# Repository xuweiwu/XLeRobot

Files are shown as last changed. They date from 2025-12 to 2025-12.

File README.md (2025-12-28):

# [XLeRobot 🤖](https://xlerobot.readthedocs.io/en/latest/index.html)




<a href="https://xlerobot.readthedocs.io/en/latest/index.html">
  front
</a>





---

**🚀 Bringing Embodied AI to Everyone - Cheaper Than an iPhone! 📱**  
**💵 Starts from $660 cost and ⏰ <4hrs total assembly time!!**

*Built upon the giants: [LeRobot](https://github.com/huggingface/lerobot), [SO-100/SO-101](https://github.com/TheRobotStudio/SO-ARM100), [Lekiwi](https://github.com/SIGRobotics-UIUC/LeKiwi), [Bambot](https://github.com/timqian/bambot)*

<table>
  <tr>
    <td></td>
    <td></td>
    <td></td>
  </tr>
  <tr>
    <td></td>
    <td></td>
    <td></td>
  </tr>
  <tr>
    <td></td>
    <td></td>
    <td></td>
  </tr>
</table>

---

# 📰 News 
- 2025-12-02: [Dual-wheel version released](https://github.com/Vector-Wangel/XLeRobot/blob/main/hardware/XLeRobot_0_4_0_extra.stl)! Have a more stable and accurate differential-wheel base for a cheaper price. (Default servo motor, optional scooter brushless Motor available at a similar price)
  

- 2025-11-11: **[Temporary VLA tutorial](https://xlerobot.readthedocs.io/en/latest/software/getting_started/RL_VLA.html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)** out. Official version out soon.
- 2025-09-22: **Hardware Assembly Video Tutorial** availabe at [Youtube](https://www.youtube.com/watch?v=upB1CEFeOlk) and [Bilibili](https://www.bilibili.com/video/BV1AGWFzUEJf/). Thanks WOWROBO for making this video!
- 2025-09-09: **Developer Assembly kit (excluding battery and IKEA cart) ready for purchase** in [China (Taobao) for **3699￥**](https://e.tb.cn/h.SZFbBgZABZ8zRPe?tk=ba514rTBRjQ) and [world-wide for **579\$**](https://shop.wowrobo.com/products/xlerobot-dual-arm-mobile-household-robot-kit?variant=47297659961561). _(In collaboration with **Wowrobo**)_
  
  - Non-profit, I personally don't earn any from this. I also asked Wowrobo to set the price as low as possible.
  - This is only the assembly kit for developers, please check documentation website and this repo for available codes and tutorials before you purchase.
- 2025-09-09: Joined [Embodied AI Home Robot Hackathon](https://www.seeedstudio.com/embodied-ai-worldwide-hackathon-home-robot.html) (Oct 25–26, Bay Area) held by **SEEED x Nvidia x Huggingface** as mentor! [Register HERE](https://docs.google.com/forms/d/e/1FAIpQLSdYYDegdgIypxuGJNLcoc8kbdmU4jKgl49zg4X-107LAmBN4g/viewform).
- 

- 2025-08-30: XLeRobot 0.3.0 Release with final outfit touch up and household chores showcase demos. 

- 2025-07-30: [Control XLeRobot in real life](https://xlerobot.readthedocs.io/en/latest/software/index.html) with **keyboard/Xbox controller/Switch joycon** in the wild anywhere. All bluetooth, no wifi needed and zero latency.

- 2025-07-08: [**Simulation**](https://xlerobot.readthedocs.io/en/latest/simulation/index.html) with updated urdfs, control scripts (support Quest3 VR, keyboard, Xbox controller, switch joycon), support for new hardware and cameras, RL environment. Get started in 15 min.
-  vr

- 2025-07-01: [**Documentation** website](https://xlerobot.readthedocs.io/en/latest/index.html) out for more orgainized tutorials, demos and resources.

- 2025-06-13: [**XLeRobot 0.2.0**](https://xlerobot.readthedocs.io) hardware setup, the 1st version fully capable for autonomous household tasks, starts from 660$. 

---

## 💵 Total Cost 💵

> [!NOTE] 
> Cost excludes 3D printing, tools, shipping, and taxes.

| Price (Buy all the parts yourself) | US | EU | CN | IN |
| --- | --- | --- | --- | --- |
| **Basic** (use your laptop, single RGB head cam) | **~$660** | **~€680** | **~¥3999** | **~₹87000** |
| ↑ Stereo dual-eye RGB head cam | +$30 | +€30 | +¥199 | +₹6550 |
| + RasberryPi | +$79 | +€79 | +¥399 | +₹7999 |
| ↑ RealSense RGBD head cam | +$220 | +€230 | +¥1499 | +₹35726 |

---
## 🚀 Get Started 🚀

> [!NOTE] 
> If you are totally new to programming, please spend at least a day to get yourself familiar with basic Python, Ubuntu and Github (with the help of Google and AI). At least you should know how to setup ubuntu system, git clone, pip install, use intepreters (VS Code, Cursor, Pycharm, etc.) and directly run commands in the terminals.

1. 💵 **Buy your parts**: [Bill of Materials](https://xlerobot.readthedocs.io/en/latest/hardware/getting_started/material.html)
2. 🖨️ **Print your stuff**: [3D printing](https://xlerobot.readthedocs.io/en/latest/hardware/getting_started/3d.html)
3. 🔨 ~~Avengers~~: [**Assemble**!](https://xlerobot.readthedocs.io/en/latest/hardware/getting_started/assemble.html)
4. 💻 **Software**: [Get your robot moving!](https://xlerobot.readthedocs.io/en/latest/software/index.html)

---

## Contribute

**👋 Want to contribute to XLeRobot?**
Please refer to [CONTRIBUTING.md](CONTRIBUTING.md) for guidance on how to get involved!

**Main Contributors**

- [Gaotian/Vector Wang](https://vector-wangel.github.io/)
- Jiahao Wang ,Chunbo Pan, QiLiu, Isaac Sin, Ryan Chen: Makermods team, VLA and VR integration
- [Zhuoyi Lu](https://lzhuoyi.github.io/Zhuoyi_Lu.github.io/): RL sim2real deploy, teleop on real robot (Xbox, VR, Joycon)
- Yiyang Huang: RL & VLA implementation (ongoing)
- YCP: WebUI for remote control (ongoing)
- [Lixing Zhang](lixingzhang.com): Hardware design improvements
- Nicole Yue: Documentation website setup
- Yuesong Wang: Mujoco simulation

This is just a small brick in the pyramid, made possible by [LeRobot](https://github.com/huggingface/lerobot), [SO-100](https://github.com/TheRobotStudio/SO-ARM100), [Lekiwi](https://github.com/SIGRobotics-UIUC/LeKiwi), and [Bambot](https://github.com/timqian/bambot). Thanks to all the talented contributors behind these detailed and professional projects.

Looking forward to collaborating with anyone interested in contributing to this project!

## About me

[Gaotian/Vector Wang](https://vector-wangel.github.io/)

I am a CS graduate student at Rice University [RobotPi Lab](https://robotpilab.github.io/), focusing on robust object manipulation, where we propse virtual cages and funnels and physics-aware world models to close the Sim2real gap and achieve robust manipulation under uncertainties. One of my papers, Caging in Time, has recently been accepted by International Journal of Robotics Research (IJRR).

I built XLeRobot as a personal hobby to instantiate my research theory, also to provide a low-cost platform for people who are interested in robotics and embodied AI to work with. 

Star History Chart (https://star-history.com/#Vector-Wangel/XLeRobot&Timeline)
---

## Citation

If you want, you can cite this work with:

```bibtex
@misc{wang2025xlerobot,
    author = {Wang, Gaotian and Lu, Zhuoyi},
    title = {XLeRobot: A Practical Low-cost Household Dual-Arm Mobile Robot Design for General Manipulation},
    howpublished = "\url{https://github.com/Vector-Wangel/XLeRobot}",
    year = {2025}
}
```
---Generated Image August 27, 2025 - 4_58PM

## 🪧 Disclaimer 🪧

> [!NOTE]
> If you build, buy, or develop a XLeRobot based on this repo, you will be fully responsible for all the physical and mental damages it does to you or others.

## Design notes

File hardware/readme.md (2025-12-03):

Here stores the .3mf file of XLeRobot 0.3.0 for 3D printing.



Note that the 3D Printing files are only to store the models. It’s suggested to place, orient, and add supports yourself to ensure the best printing quality.

## Notes
- New release on XLeRobot 0.4.0: dual-wheel setup, more versatile arm base (choose your own mounting direction).
- The .3mf file contains soft finray fingers that need to be printed with TPU95A. If you want original SO101 finger, just download the original SO101 .stl file.
- d2e57534a9e55a3d4dc0d644242cd044
- The .3mf file contains 2 version of the single RGB head camera connector and shell, one for webcam & realsense, the other for the cheaper camera same as the hand camera.
- 

- No need to adjust the base connector this time, just print the washers and insert them into the IKEA cart for the best base support.
- 

---

- Update 20.09.2025 by Lix: New gimbal designs can be found in the two mesh files:
    - Gimbal_Pitch_Holder_d435.stl: For Intel Realsense D435 or similar RGBD camera.
    - Gimbal_Pitch_Holder_d455.stl: For Intel Realsense D455 or similar RGBD camera.

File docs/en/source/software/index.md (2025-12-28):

<!-- THIS IS ALL GENERATED DOCUMENTATION via generate_robot_docs.py. DO NOT MODIFY THIS FILE DIRECTLY. -->

# Software

Here we will show how to run XLeRobot under the lerobot framework.

### [Install LeRobot 🤗 and Move XLeRobot files](getting_started/install.md)

### Quick Guide

```{note}
If you haven't played with lerobot SO101 Arm before, it's recommended to test single arm setup teleop and play with it for a while first.
```

1. **Choose Control Method**: Joint control (example 0) for basic motor testing, end-effector control for teleop (example 1 & 6)
2. **Advanced Features**: Try dual-arm control (example 2) or vision-based control (example 3) for more complex tasks
3. **Full System**: Use keyboard (example 4), Xbox controller (example 5), or Switch Joycon (example 7) for complete XLeRobot teleop

All example scripts are located in the [`software/examples/`](https://github.com/Vector-Wangel/XLeRobot/tree/main/software/examples) directory and can be run directly after proper setup and calibration. Some examples needs additional calibration to ensure performance.

```{note}
For basic version of XLeRobot, you don't need a RaspberryPi. Just use your laptop and put it in the IKEA cart if you want to use the full system.
```

### [SO100/SO101 Arm Examples](getting_started/SO101.md)

### [XLeRobot Teleop](getting_started/XLeRobot_teleop.md)

### [Autonomous LLM Agent](getting_started/LLM_agent.md)

```{note}
The VLA tutorials below came from different teams in the community. Thanks a lot for their efforts!
```

### [VLA (1) ACT](getting_started/VLA_ACT.md)

### [VLA (2) SmolVLA)](getting_started/VLA_smol.md)

### [VLA (3) pi0.5)](getting_started/VLA_pi05.md)

### [Reinforcenment Learning (RL)](getting_started/RL.md)

### [Raspberri Pi Setup](getting_started/raspberry_pi_setup.md)

```{toctree}
getting_started/install
getting_started/SO101
getting_started/XLeRobot_teleop
getting_started/LLM_agent
getting_started/VLA_ACT
getting_started/VLA_smol
getting_started/VLA_pi05
getting_started/RL
getting_started/raspberry_pi_setup.md
```

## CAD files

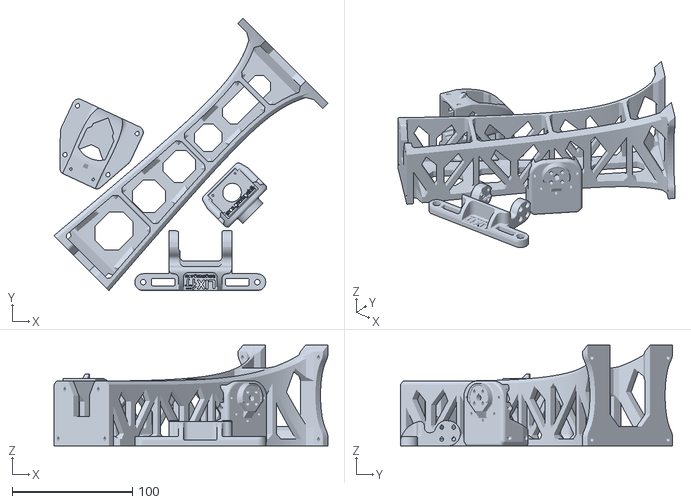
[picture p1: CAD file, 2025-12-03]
hardware/camera_connector/Gimbal_mesh_all_d455.stl
228.0 x 226.5 x 84.0

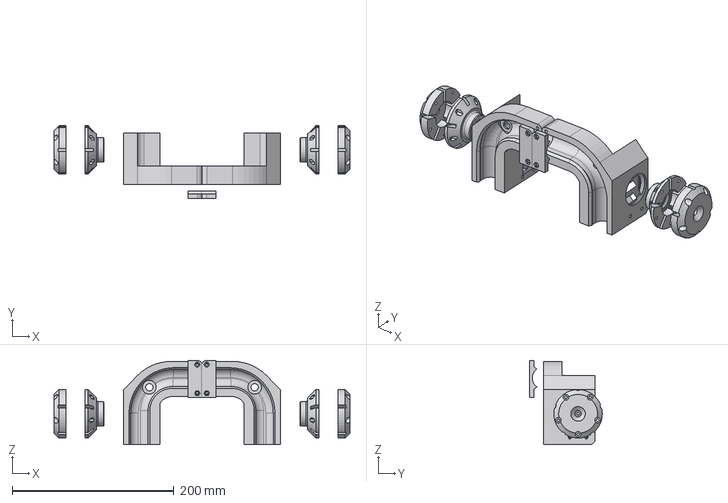
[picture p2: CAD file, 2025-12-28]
hardware/step/XLeRobot_040/XLeRobot040_dualwheelbase.step
366.3 x 89.9 x 104.3 mm
Circular Pattern 01
omni_wheel_mount v5:3

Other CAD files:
hardware/camera_connector/Gimbal_mesh_all_d435.stl

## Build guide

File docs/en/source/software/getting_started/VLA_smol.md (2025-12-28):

# VLA (2) SmolVLA, ACT

This document explains how to use **XLeRobot** for:
1. Training and running **SmolVLA** with a **bimanual SO-101** setup and **three-camera data collection**
2. Training and running **ACT (Action Chunking with Transformers)** policy
3. Using **VR Control** for XLeRobot
VR Demo GIF
VR Demo GIF
---

## 1) Overview

XLeRobot is a LeRobot-based setup that adds:
- **BiSO101Follower** (bimanual follower arm)
- **BiSO101Leader** (bimanual teleoperation/leader arm)
- **Independent** control of left/right arms + **synchronized** bimanual operation
- **Three-camera** recording configuration:
  - `front_cam`
  - `hand_cam`
  - `side_cam`
 

### References
- [SmolVLA base model](https://huggingface.co/lerobot/smolvla_base)
- [ACT documentation](https://huggingface.co/docs/lerobot/en/act)
- [XLeRobot / LeRobot fork usage](https://github.com/kahowang/lerobot)
- [Rumi](https://github.com/MakerModsRobotics/Rumi)
- [XLeRobot improvement upgrades](https://github.com/MakerModsRobotics/xlerobot_improvements)

---

## 2) Demo Tasks (What SmolVLA Can Learn with ~20 Episodes)

### Demo 1 - Drawer + Pick + Place + Grasp (Bimanual)
After training on **~20 episodes**, XLeRobot can:
1. Pull open a drawer
2. Pick an object
3. Place the object into the drawer
4. Push the drawer in

VR Demo GIF

**Key aspects:**
- **One-shot grasp** of the drawer handle (avoid jitter during data collection)
- While the **left arm** pulls the drawer, the **right arm** must **precisely** grasp the object's center
- **Accurate one-shot placement** into the drawer and smooth "push-in" close

### Demo 2 - Pencil Case Zipper (Fine Manipulation)
After training on **~20 episodes**, XLeRobot can:
1. Grasp the zipper pull tab
2. Grasp the pencil case handle and stabilize the case
3. Pull the zipper tab to open the zipper smoothly

VR Demo GIF

**Key difficulties:**
- The zipper pull is often in a **top-down camera blind spot**, requiring **one-shot** grasp (avoid re-grasp)
- Maintain consistent pulling height to avoid lifting up/down (no "upward yank" or "downward drag")

---

## 3) Hardware / Configuration Notes

### Camera Placement (Three Cameras)
Recommended configuration:
- `front_cam` × 1
- `hand_cam` × 1
- `side_cam` × 1

> **Note:** In practice, consistent camera placement and stable lighting are critical for learning stable manipulation.

### Action Dimension Handling (Important)
A bimanual SO-101 robot has **12 action dimensions**:
- 6 joints × 2 arms = **12**

**SmolVLA automatically detects and handles action dimensions** without manual configuration:
- During training: **12-D → padded to 32-D** (`max_action_dim`)
- During inference: **32-D → cropped back to original 12-D**

**Conceptual code path:**
```python
# Training: 12D -> pad to 32D
actions = pad_vector(batch[ACTION], self.config.max_action_dim)

# Inference: 32D -> crop back to 12D
original_action_dim = self.config.action_feature.shape[0]  # auto-detected: 12
actions = actions[:, :, :original_action_dim]
```

Unlike other VLA models (e.g., xVLA) that may require manual `action_mode` configuration, SmolVLA's dynamic padding supports any action space ≤ 32D.

---

## 4) Installation & Environment Setup (Linux)

### A. Install Miniconda (Example)
```bash
wget https://repo.anaconda.com/miniconda/Miniconda3-latest-Linux-x86_64.sh
bash Miniconda3-latest-Linux-x86_64.sh

# Restart terminal, then verify
conda --version
```

### B. Create & Activate Environment
```bash
conda create -n lerobot python=3.10
conda activate lerobot
```

> **Note:** Activate this environment every time you use LeRobot/XLeRobot:
> ```bash
> conda activate lerobot
> ```

### C. Install System Dependencies (FFmpeg)
```bash
conda install -c conda-forge ffmpeg
```

### D. Clone Repository & Install Dependencies
```bash
git clone https://github.com/kahowang/lerobot.git
cd lerobot

# Install LeRobot with Feetech motor support (required for SO-101)
pip install -e ".[feetech]"

# Install SmolVLA dependencies
pip install -e ".[smolvla]"
```

---

## 5) Data Collection (Three-Camera, Bimanual Teleop)

Use `lerobot-record` to record bimanual demonstrations with three cameras.

Replace `${HF_USER}` and `your_dataset_name` with your Hugging Face username and dataset name.

```bash
lerobot-record \
  --robot.type=bi_so101_follower \
  --robot.left_arm_port=/dev/ttyACM0 \
  --robot.right_arm_port=/dev/ttyACM1 \
  --robot.id=bimanual_follower \
  --robot.cameras='{
    "front_cam": {"type": "opencv", "index_or_path": 0, "width": 640, "height": 480, "fps": 30},
    "hand_cam": {"type": "opencv", "index_or_path": 1, "width": 640, "height": 480, "fps": 30},
    "side_cam": {"type": "opencv", "index_or_path": 2, "width": 640, "height": 480, "fps": 30}
  }' \
  --teleop.type=bi_so101_leader \
  --teleop.left_arm_port=/dev/ttyACM2 \
  --teleop.right_arm_port=/dev/ttyACM3 \
  --teleop.id=bimanual_leader \
  --dataset.repo_id=${HF_USER}/your_dataset_name \
  --dataset.single_task="Your task description here" \
  --dataset.num_episodes=50
```

### Parameter Tips
1. Ports (`/dev/ttyACM*`) must match your actual USB device mapping
2. `dataset.single_task` should be concise but specific (improves reproducibility)
3. For quick iteration, start with 20 episodes and scale up

---

## 6) Training Policies

### 6.1) Train SmolVLA

```bash
lerobot-train \
  --policy.path=lerobot/smolvla_base \
  --dataset.repo_id=${HF_USER}/your_dataset_name \
  --batch_size=64 \
  --steps=20000 \
  --output_dir=outputs/train/smolvla_three_cameras \
  --job_name=smolvla_training_three_cameras \
  --policy.device=cuda \
  --wandb.enable=true
```

**Notes:**
1. `--policy.path=lerobot/smolvla_base` points to the SmolVLA base policy
2. Adjust `--steps` based on dataset size and task complexity
3. If you do not have a GPU, set `--policy.device=cpu` (training will be slow)

### 6.2) Train ACT (Action Chunking with Transformers)

ACT is an imitation-learning method that predicts short action chunks instead of single steps. It often achieves high success rates with teleoperated data.

**Basic Training Command:**
```bash
python -m lerobot.scripts.train \
  --dataset.repo_id=${HF_USER}/your_dataset_name \
  --policy.type=act \
  --output_dir=outputs/train/act_bimanual_demo \
  --job_name=act_training_bimanual \
  --policy.device=cuda \
  --policy.repo_id=${HF_USER}/act_bimanual_demo \
  --wandb.enable=true
```

**Alternative using `lerobot-train`:**
```bash
lerobot-train \
  --policy.type=act \
  --dataset.repo_id=${HF_USER}/your_dataset_name \
  --output_dir=outputs/train/act_bimanual_demo \
  --job_name=act_training_bimanual \
  --policy.device=cuda \
  --wandb.enable=true
```

**Training Notes:**
- Checkpoints are written to `outputs/train/<job_name>/checkpoints/`
- ACT typically trains in a few hours on a single GPU (~80M parameters)
- A checkpoint at 80k steps takes about 1h45 on an Nvidia A100
- For Apple Silicon: use `--policy.device=mps`

**Resume Training from Checkpoint:**
```bash
python -m lerobot.scripts.train \
  --config_path=outputs/train/act_bimanual_demo/checkpoints/last/pretrained_model/train_config.json \
  --resume=true
```

---

## 7) Inference/Evaluation

### 7.1) SmolVLA Inference

Typical pattern to run policy inference and log evaluation episodes:

```bash
lerobot-record \
  --robot.type=bi_so101_follower \
  --robot.left_arm_port=/dev/ttyACM0 \
  --robot.right_arm_port=/dev/ttyACM1 \
  --robot.id=bimanual_follower \
  --robot.cameras='{
    "front_cam": {"type": "opencv", "index_or_path": 0, "width": 640, "height": 480, "fps": 30},
    "hand_cam": {"type": "opencv", "index_or_path": 1, "width": 640, "height": 480, "fps": 30},
    "side_cam": {"type": "opencv", "index_or_path": 2, "width": 640, "height": 480, "fps": 30}
  }' \
  --dataset.single_task="Your task description here" \
  --dataset.repo_id=${HF_USER}/eval_results \
  --dataset.num_episodes=10 \
  --policy.path=${HF_USER}/smolvla_three_cameras
```

**Notes:**
1. `--policy.path` should point to your trained policy checkpoint / uploaded policy
2. `eval_results` is a separate dataset repo for evaluation logs (recommended)

### 7.2) ACT Inference

**Using `lerobot-record`:**
```bash
lerobot-record \
  --robot.type=bi_so101_follower \
  --robot.left_arm_port=/dev/ttyACM0 \
  --robot.right_arm_port=/dev/ttyACM1 \
  --robot.id=bimanual_follower \
  --robot.cameras='{
    "front_cam": {"type": "opencv", "index_or_path": 0, "width": 640, "height": 480, "fps": 30},
    "hand_cam": {"type": "opencv", "index_or_path": 1, "width": 640, "height": 480, "fps": 30},
    "side_cam": {"type": "opencv", "index_or_path": 2, "width": 640, "height": 480, "fps": 30}
  }' \
  --dataset.single_task="Your task description here" \
  --dataset.repo_id=${HF_USER}/eval_act_results \
  --dataset.num_episodes=10 \
  --policy.path=${HF_USER}/act_bimanual_demo
```

**Using `python -m lerobot.record`:**
```bash
python -m lerobot.record \
  --robot.type=bi_so101_follower \
  --robot.left_arm_port=/dev/ttyACM0 \
  --robot.right_arm_port=/dev/ttyACM1 \
  --dataset.repo_id=${HF_USER}/eval_act_results \
  --policy.path=${HF_USER}/act_bimanual_demo \
  --episodes=10
```

**Notes:**
- The policy will execute autonomously on the robot
- Evaluation results are saved to the specified dataset repo
- Compare evaluation episodes with training demonstrations to assess performance

---

## 8) VR Control for XLeRobot

VR Demo GIF

### Robot: Rumi
Rumi is a new-generation bimanual robot with a liftable chassis:
[Rumi](https://www.makermods.ai/rumi)

RUMI_HEAD_VR

### Repositories
1. [VR controller repo](https://github.com/IIMFINE/lerobot_vr_controller.git)
2. [LeRobot repo (fork)](https://github.com/IIMFINE/lerobot.git)

### Features
1. VR → robot arm mapping
2. Supports:
   - Inverse kinematics (IK) solving
   - Joint-space → motor command conversion

### XLeRobot integrates ROS 2
For VR control, follow the repository's README to configure VR devices, ROS 2 nodes, and robot drivers.

---

VR Demo GIF

## 9) Practical Tips / Common Pitfalls

### Data Quality
1. Aim for one-shot grasps during demonstrations (avoid micro-corrections)
2. Keep camera viewpoints consistent between recording and inference
3. Maintain stable lighting and avoid motion blur

### Bimanual Coordination
For tasks like drawers:
- **Left arm:** stable pulling trajectory
- **Right arm:** precise pick/place with minimal hesitation

VR Demo GIF

### Device Ports
If ports change after reboot, consider using persistent udev rules to stabilize device naming.
---

VR Demo GIF

## 10) Quick Checklist

- [ ] `conda activate lerobot`
- [ ] Three cameras connected and indices correct (0/1/2)
- [ ] Follower ports correct (`/dev/ttyACM0`, `/dev/ttyACM1`)
- [ ] Leader ports correct (`/dev/ttyACM2`, `/dev/ttyACM3`)
- [ ] Dataset repo ID and task description set
- [ ] Training runs on correct device (cuda vs cpu)
- [ ] Inference uses the correct trained policy path

---

<video width="100%" controls>
  <source src="https://vector-wangel.github.io/XLeRobot-assets/videos/Community/makermod/makermod.mp4" type="video/mp4">
  Your browser does not support the video tag.
</video>

## Appendix: Links

### Official Documentation
- [LeRobot Docs](https://huggingface.co/docs/lerobot)
- [ACT Documentation](https://huggingface.co/docs/lerobot/en/act)
- [Imitation Learning on Real-World Robots](https://huggingface.co/docs/lerobot/il_robots)
- [Getting Started with Real-World Robots](https://huggingface.co/docs/lerobot/en/getting_started_real_world_robot)

### Models & Repositories
- [SmolVLA base](https://huggingface.co/lerobot/smolvla_base)
- [ACT example model](https://huggingface.co/lerobot/act_aloha_sim_transfer_cube_human)
- [XLeRobot fork usage](https://github.com/kahowang/lerobot)
- [Rumi robot](https://www.makermods.ai/rumi)
- [VR controller](https://github.com/IIMFINE/lerobot_vr_controller.git)
- [LeRobot fork](https://github.com/IIMFINE/lerobot.git)

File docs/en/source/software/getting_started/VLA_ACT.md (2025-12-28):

## VLA (1) ACT

Single arm VLA policy implementation on XLeRobot:

<video width="100%" controls>
  <source src="https://vector-wangel.github.io/XLeRobot-assets/videos/Real_demos/Act_on_RPi_Xle.mp4" type="video/mp4">
  Your browser does not support the video tag.
</video>

# Vision-Language-Action (VLA) Training for XLeRobot

This tutorial will guide you through the process of training a Vision-Language-Action (VLA) model to control your XLeRobot arms autonomously. As control devices we will use VR and leader arm. If you want us to add more control devices (as xbox controller or keyboard) feel free to open an issue.

## What You'll Learn

1. How to teleoperate and record demonstration datasets for XLeRobot
2. How to train and evaluate your policy
3. How to make the policy work effectively

By following these steps, you'll be able to train your XLeRobot to autonomously perform various household tasks using LeRobot policies (such as ACT), including picking up objects, wiping tables, or organizing items.

---

## 1. Hardware Setup and Check

### 1.1 Turn the head camera to an appropriate angle

For both VLA dataset collection and inference you need to keep consistent head servos angles - otherwise policy will not work or performance will drop.

Also, ensure the camera fully sees arms operation field - if for example your policy takes object from table and puts it into robot basket - both table and basket need to be fully visible.

You can turn the camera by your hand or use utility from RoboCrew lib (especially if you want to use your VLA policy as LLM agent tool) - this will provide you with a perfect repeatability of the camera angle:

```python
from robocrew.robots.XLeRobot.servo_controls import ServoControler

servo_controler = ServoControler(left_arm_head_usb='/dev/arm_left')
servo_controler.turn_head_to_vla_position()
```

### 1.2 Check Camera Status

Use the LeRobot [cameras](https://huggingface.co/docs/lerobot/cameras) tutorial to verify your camera setup:

```bash
lerobot-find-cameras opencv  # or use 'realsense' for Intel RealSense cameras
```

You should see output similar to this:

```
--- Detected Cameras ---
Camera #0:
  Name: OpenCV Camera @ 0
  Type: OpenCV
  Id: 0
  Backend api: AVFOUNDATION
  Default stream profile:
    Format: 16.0
    Width: 1920
    Height: 1080
    Fps: 15.0
--------------------
(more cameras ...)
```

XLeRobot has three cameras: two wrist cameras and one head camera. Make sure all three are detected.

---

## 2.1. Record Dataset for a Single Arm Using a Leader Arm

Very often the single arm is enough to perform your pick-and-place task. Using single arm only means using less servos and cameras, so it will be much easier for your model to learn the policy. If your task is simple enough to be done with one arm - let's train policy for it.

Connect a leader arm to the Raspberry Pi or other computer you use to record a dataset.

Following script will start recording:

```bash
python /your_dir/lerobot/src/lerobot/record.py \
  --robot.type=so101_follower \
  --robot.port=/dev/right_arm \
  --robot.id=robot_right_arm \
  --robot.cameras="{ head: {type: intelrealsense, serial_number_or_name: 935422072196, width: 640, height: 480, fps: 30, use_depth: True}, right: {type: opencv, index_or_path: '/dev/video6', width: 640, height: 480, fps: 30}}" \
  --teleop.type=so101_leader \
  --teleop.port=/dev/ttyACM0 \
  --teleop.id=my_leader_arm \
  --display_data=true \
  --dataset.repo_id=your_huggingface_id/clear_table_single_arm \
  --dataset.num_episodes=50 \
  --dataset.single_task="Clear the table"
```

## 2.2. Record Dataset for XLeRobot with VR

For more complicated policies, let's use VR to activate both robot's arms and wheels.

Before the official merge into LeRobot, copy the required code from XLeRobot to LeRobot:
```bash
cp your_dir/XLeRobot/software/src/record.py your_dir/lerobot/src/lerobot/record.py
cp your_dir/XLeRobot/software/src/teleporators/xlerobot_vr your_dir/lerobot/src/lerobot/teleporators/xlerobot_vr -r
```

### Recording Script Example

Run the following script to start recording:

```bash
python /your_dir/lerobot/src/lerobot/record.py \
  --robot.type=xlerobot \
  --robot.cameras="{ head: {type: intelrealsense, serial_number_or_name: 935422072196, width: 640, height: 480, fps: 30, use_depth: True}, right: {type: opencv, index_or_path: '/dev/video6', width: 640, height: 480, fps: 20}, left: {type: opencv, index_or_path: '/dev/video8', width: 640, height: 480, fps: 20} }" \
  --dataset.repo_id=your_huggingface_id/clear_table \
  --dataset.single_task="Clear the table." \
  --dataset.root=your_dir/clear_table \
  --display_data=true \
  --teleop.type=xlerobot_vr
```

### Important Notes

1. **Camera Configuration**: The `robot.cameras` parameter should match the output from section 1.2. If you encounter camera timeout errors, reduce the FPS (e.g., from 30 to 20).

2. **VR Connection**: At the beginning of the script, it will wait for VR connection. Visit the URL displayed in the terminal output using your VR device. Data collection will start automatically once the connection is established.

3. **VR Controls**: The left-hand controller has four functions (practice several times to become familiar):
   - **Reset Position**: Returns the robot arms to their zero position
   - **Early Exit**: Ends the current episode collection (use when you've completed the task)
   - **Delete Episode**: Deletes the current episode (use if the task failed)
   - **Stop Recording**: Stops the dataset recording session

<p align="center">
  
  
</p>

---

```{note}
Some tips for a better performance:

1. **Check for Dropped Frames**: Review [these examples](https://gold-column-7d2.notion.site/Some-examples-for-VLA-dataset-2a2e20e657ad8037aa09d1228a2bf4bf?pvs=73) to understand what dropped frames look like. Monitor your bandwidth and CPU usage during recording. If issues occur, optimize your system accordingly.

2. **Avoid Redundant Frames**: Use the early exit function when the task is completed, rather than letting the script continue logging static robot data.

3. **Maintain Scene Consistency**: Avoid having additional moving objects or people in the camera view during recording.
```
---

## 3. Train a Policy

After collecting your datasets, refer to the LeRobot [training tutorial](https://huggingface.co/docs/lerobot/il_robots#train-a-policy) to select and train a policy.

## 4. Deploy a Model

The simplest way to test your trained model:
```python
python /your_dir/lerobot/src/lerobot/record.py \
  --robot.type=xlerobot \
  --robot.cameras="{ head: {type: intelrealsense, serial_number_or_name: 935422072196, width: 640, height: 480, fps: 30, use_depth: True}, right: {type: opencv, index_or_path: '/dev/video6', width: 640, height: 480, fps: 20}, left: {type: opencv, index_or_path: '/dev/video8', width: 640, height: 480, fps: 20} }" \
  --dataset.repo_id=your_huggingface_id/clear_table \
  --dataset.single_task="Clear the table." \
  --dataset.root=your_dir/clear_table \
  --display_data=true \
  --teleop.type=xlerobot_vr
```

Script above runs policy locally on your robot's Raspberry. For lightweight ACT policy it's enough, but for other more resource-consuming policies, the Raspberry will not provide enough computation. 

To run powerful policies as SmolVLA or PI0,5 we need an external computer with GPU. Follow the Lerobot [async inference guide](https://huggingface.co/docs/lerobot/async) to set up policy server on your PC, and client on the XLeRobot. Use loopback interface (0.0.0.0) instead of localhost for your server, and provide server's local IP to the client.

In most cases you'll want to use your VLA policy not by itself, but as a tool of the [LLM agent](https://xlerobot.readthedocs.io/en/latest/software/getting_started/LLM_agent.html). RoboCrew lib already provides you with async client in the tool. Before using it, remember to run policy server on the server machine:

```
python -m lerobot.async_inference.policy_server \
     --host=0.0.0.0 \
     --port=8080
```

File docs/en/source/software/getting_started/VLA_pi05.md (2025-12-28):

# VLA (3) pi0.5

<video width="100%" controls>
  <source src="https://vector-wangel.github.io/XLeRobot-assets/videos/Community/pi05_XLeRobot.mp4" type="video/mp4">
  Your browser does not support the video tag.
</video>

This document provides information about the **pi0.5** VLA (Vision-Language-Action) implementation for XLeRobot with dual-arm support.

## Overview

The pi0.5 implementation includes optimizations for data collection scripts and dual-arm teleoperation, data collection, and inference workflows. Some changes are available in local branches for reference.

## Implementation Details

### XLeRobot Fork
- **Repository**: [xuweiwu/XLeRobot](https://github.com/xuweiwu/XLeRobot)
- **Branch**: `pi05 dual arm`
- **Features**: Teleoperation, data collection, and inference for dual-arm setup

### OpenPI Fine-tuning
- **Repository**: [xuweiwu/openpi](https://github.com/xuweiwu/openpi)
- **Branch**: `biso101 training_support`
- **Features**: Training support for bimanual SO-101 configuration

## Status

A minor PR has been created to optimize the existing data collection script workflow. Additional changes that may be more difficult to merge are currently available in local branches for reference.

## Related Links

- [XLeRobot Fork (pi0.5)](https://github.com/xuweiwu/XLeRobot)
- [OpenPI Fork (biso101 training)](https://github.com/xuweiwu/openpi)

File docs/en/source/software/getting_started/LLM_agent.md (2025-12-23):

## LLM Agent Control

Imagine telling the robot "go cleanup my kitchen" and watching it doing so. This tutorial will show you how you can make your XLeRobot fully autonomous, self-decision making machine by providing it with LLM agent. An agent that uses camera vision and voice commands to move the robot and manipulate objects with VLA policies.

Demo of agent controlling XLeRobot, that has a task to grab a notebook and give it to human:

<video width="100%" controls>
  <source src="https://github-production-user-asset-6210df.s3.amazonaws.com/50213363/528949330-faf375cf-d29a-4b1b-b0b1-da474c7006fe.mov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" type="video/mp4">
  To be uploaded.
</video>

### Getting Started

To create our agent, we will use the [RoboCrew](https://github.com/Grigorij-Dudnik/RoboCrew) library - one specially designed for embodied agents. On your control device (Raspberry Pi or laptop) create a new virtual environment and install it with:

```bash
pip install robocrew
```

Next, create the python script to control your robot. Let's start by creating a simple agent that performs just one hardcoded task and finishes. 

First, let's initialize camera and create tools for agent to control a wheel movement:

```python
from robocrew.core.camera import RobotCamera
from robocrew.core.LLMAgent import LLMAgent
from robocrew.robots.XLeRobot.tools import create_move_forward, create_turn_right, create_turn_left
from robocrew.robots.XLeRobot.servo_controls import ServoControler

# set up main camera
main_camera = RobotCamera("/dev/camera_center") # camera usb port Eg: /dev/video0

#set up servo controler
right_arm_wheel_usb = "/dev/arm_right"    # provide your right arm usb port. Eg: /dev/ttyACM1
servo_controler = ServoControler(right_arm_wheel_usb=right_arm_wheel_usb)

#set up tools
move_forward = create_move_forward(servo_controler)
turn_left = create_turn_left(servo_controler)
turn_right = create_turn_right(servo_controler)
```

in place of `/dev/arm_right` you should provide the USB port name of your right arm (one connected to the wheels).

Next, let's initialize and run an agent itself:

```python
# init agent
agent = LLMAgent(
    model="google_genai:gemini-3-flash-preview",
    tools=[
        move_forward,
        turn_left,
        turn_right,
    ],
    main_camera=main_camera,
    servo_controler=servo_controler,
)

agent.task = "Approach a human."

agent.go()
```

In the code above we initialized our agent with the maneuver tools we created earlier. You can provide any model in LangChain notation. Next, we hard-coding a task for our agent and running it.

Before going to LLM, camera image is specially augmented to make it easier for robot to understand its environment: 

<div style="text-align: center; font-style: italic">
  
  <p>That's how your robot sees the world.</p>
</div>

Also, create the `.env` file with parameter `GOOGLE_API_KEY=<your gemini api key here>` beside the script to connect to LLM.

Now run the code and watch your XLeRobot approaching you - then it will finish its work by calling `finish_task` tool!

Complete code is here:

```python
from robocrew.core.camera import RobotCamera
from robocrew.core.LLMAgent import LLMAgent
from robocrew.robots.XLeRobot.tools import create_move_forward, create_turn_right, create_turn_left
from robocrew.robots.XLeRobot.servo_controls import ServoControler

# set up main camera
main_camera = RobotCamera("/dev/camera_center") # camera usb port Eg: /dev/video0

#set up servo controler
right_arm_wheel_usb = "/dev/arm_right"    # provide your right arm usb port. Eg: /dev/ttyACM1
left_arm_head_usb = "/dev/arm_left"      # provide your left arm usb port. Eg: /dev/ttyACM0
servo_controler = ServoControler(right_arm_wheel_usb, left_arm_head_usb)

#set up tools
move_forward = create_move_forward(servo_controler)
turn_left = create_turn_left(servo_controler)
turn_right = create_turn_right(servo_controler)

# init agent
agent = LLMAgent(
    model="google_genai:gemini-3-flash-preview",
    tools=[move_forward, turn_left, turn_right],
    main_camera=main_camera,
    servo_controler=servo_controler,
)

agent.task = "Approach a human."

agent.go()
```

### Set up Udev rules

Before proceeding to more advanced examples, let's do optional, but highly recommended step - make the usb port names for arms and cameras constant, to avoid swapping those names after every Raspberry Pi reboot. To do it, we need to set up udev rules. Luckily, RoboCrew already contains an utility that makes a complicated process of setting up udevs a matter of few clicks.

Run:

```bash
robocrew-setup-usb-modules
```

Utility will ask you to disconnect all usbs and then connect one after another - that way your usb devices will receive a constant names.

### Voice-conrolled agent

We managed to run our simple agent, now let's give it an ability to listen to our voice commands through the microphone.

First, we need to install Portaudio, to enable our control device to hear:

```bash
sudo apt install portaudio19-dev
```

Connect to your agent a soundcard with microphone, and optionally speaker, if you want robot to respond to you.

Let's change the agent initialization a little bit:

```python
agent = LLMAgent(
    model="google_genai:gemini-3-flash-preview",
    tools=[move_forward, turn_left, turn_right],
    main_camera=main_camera,
    servo_controler=servo_controler,
    sounddevice_index=2,    # provide your microphone device index.
    wakeword="hey robot",   # optional - set up custom wakeword (default is "robot")
    tts=True,               # enable text-to-speech (robot can speak).
)

agent.go()
```

As you can see, we need to provide index of our soundcard with microphone. We can also set up a wakeword (default is "robot") - when robot hears that word in your sentence, it treats sentence as a new task; otherwise ignores it.

`tts=True` is needed if you want robot to speak.

We can also set up `history_len` - how many of last movements robot should keep in the memory, to avoid memory overflow.

Run the code and ask the robot to go somewhere!

Complete code is here:

```python
from robocrew.core.camera import RobotCamera
from robocrew.core.LLMAgent import LLMAgent
from robocrew.robots.XLeRobot.tools import create_move_forward, create_turn_right, create_turn_left
from robocrew.robots.XLeRobot.servo_controls import ServoControler

# set up main camera
main_camera = RobotCamera("/dev/camera_center") # camera usb port Eg: /dev/video0

#set up servo controler
right_arm_wheel_usb = "/dev/arm_right"    # provide your right arm usb port. Eg: /dev/ttyACM1
servo_controler = ServoControler(right_arm_wheel_usb=right_arm_wheel_usb)

#set up tools
move_forward = create_move_forward(servo_controler)
turn_left = create_turn_left(servo_controler)
turn_right = create_turn_right(servo_controler)

# init agent
agent = LLMAgent(
    model="google_genai:gemini-3-flash-preview",
    tools=[move_forward, turn_left, turn_right],
    main_camera=main_camera,
    servo_controler=servo_controler,
    sounddevice_index=2,    # provide your microphone device index.
    wakeword="hey robot",   # optional - set up custom wakeword (default is "robot")
    tts=True,               # enable text-to-speech (robot can speak).
)

agent.task = "Wait for the voice commands and execute."

agent.go()
```

### Activate arm manipulation

Let's go to the most advanced and useful part of our agent - the arms manipulation through VLA policies! That allows the robot to make full range of household tasks - like throwing out a trash or bringing you a tea from kitchen.

First of all, you need to train the policy agent will utilize later. Reference [VLA tutorial](https://xlerobot.readthedocs.io/en/latest/software/getting_started/RL_VLA.html) to learn how to do it.

Let's assume you trained VLA policy that grabs a notebook from the table and put it in the robot basket (for further transportation). Let's add it as a tool for your agent:

```python
from robocrew.robots.XLeRobot.tools import create_vla_single_arm_manipulation

pick_up_notebook = create_vla_single_arm_manipulation(
    tool_name="Grab_a_notebook",
    tool_description="Manipulation tool to grab a notebook from the table and put it to your basket.",
    task_prompt="Grab a notebook.",
    server_address="0.0.0.0:8080",
    policy_name="Grigorij/act_right-arm-grab-notebook-2",
    policy_type="act",
    arm_port=right_arm_wheel_usb,
    servo_controler=servo_controler,
    camera_config={"main": {"index_or_path": "/dev/camera_center"}, "right_arm": {"index_or_path": "/dev/camera_right"}},
    main_camera_object=main_camera,
    policy_device="cpu",
)
```

Provide the tool with parameters your custom tool name and description - that's what LLM will see. Also, provide VLA-related parameters - as the name of your trained policy on HF hub, policy type, camera config (same you used during dataset collection).

Then add created `pick_up_notebook` tool to the tools of your agent.

Our tool is a policy client, but all VLA computations are run on the server side. We need to run policy server - on Raspberry Pi only in case of light-weight ACT policy, on different computer for all other policies. Run your server with:

```
python -m lerobot.async_inference.policy_server \
     --host=0.0.0.0 \
     --port=8080
```

In case you using external computer in your local network as a server, provide its IP instead of zeros to `server_address` parameter like: `server_address="123.234.12.34:8080"`

That's it! Prompt your robot to grab a cup from the table and give it to you!

In the full code, we also added more movement tools for more precision navigation:

```python
from robocrew.core.camera import RobotCamera
from robocrew.core.LLMAgent import LLMAgent
from robocrew.robots.XLeRobot.tools import \
    create_vla_single_arm_manipulation, \
    create_go_to_precision_mode, \
    create_go_to_normal_mode, \
    create_move_backward, \
    create_move_forward, \
    create_strafe_right, \
    create_strafe_left, \
    create_look_around, \
    create_turn_right, \
    create_turn_left
from robocrew.robots.XLeRobot.servo_controls import ServoControler

# set up main camera
main_camera = RobotCamera("/dev/camera_center") # camera usb port Eg: /dev/video0

#set up servo controler
right_arm_wheel_usb = "/dev/arm_right"    # provide your right arm usb port. Eg: /dev/ttyACM1
left_arm_head_usb = "/dev/arm_left"      # provide your left arm usb port. Eg: /dev/ttyACM0
servo_controler = ServoControler(right_arm_wheel_usb, left_arm_head_usb)

#set up tools
move_forward = create_move_forward(servo_controler)
move_backward = create_move_backward(servo_controler)
turn_left = create_turn_left(servo_controler)
turn_right = create_turn_right(servo_controler)
strafe_left = create_strafe_left(servo_controler)
strafe_right = create_strafe_right(servo_controler)

look_around = create_look_around(servo_controler, main_camera)
go_to_precision_mode = create_go_to_precision_mode(servo_controler)
go_to_normal_mode = create_go_to_normal_mode(servo_controler)

pick_up_notebook = create_vla_single_arm_manipulation(
    tool_name="Grab_a_notebook",
    tool_description="Manipulation tool to grab a notebook from the table and put it to your basket.",
    task_prompt="Grab a notebook.",
    server_address="0.0.0.0:8080",
    policy_name="Grigorij/act_right-arm-grab-notebook-2",
    policy_type="act",
    arm_port=right_arm_wheel_usb,
    servo_controler=servo_controler,
    camera_config={"main": {"index_or_path": "/dev/camera_center"}, "right_arm": {"index_or_path": "/dev/camera_right"}},
    main_camera_object=main_camera,
    policy_device="cpu",
)

give_notebook = create_vla_single_arm_manipulation(
    tool_name="Give_a_notebook_to_a_human",
    tool_description="Manipulation tool to take a notebook from your basket and give it to human.",
    task_prompt="Grab a notebook and give it to a human.",
    server_address="0.0.0.0:8080",
    policy_name="Grigorij/act_right_arm_give_notebook",
    policy_type="act",
    arm_port=right_arm_wheel_usb,
    servo_controler=servo_controler,
    camera_config={"main": {"index_or_path": "/dev/camera_center"}, "right_arm": {"index_or_path": "/dev/camera_right"}},
    main_camera_object=main_camera,
    policy_device="cpu",
    execution_time=45,
)

# init agent
agent = LLMAgent(
    model="google_genai:gemini-3-flash-preview",
    system_prompt=system_prompt,
    tools=[
        move_forward,
        move_backward,
        strafe_left,
        strafe_right,
        turn_left,
        turn_right,
        look_around,
        go_to_precision_mode,
        go_to_normal_mode,
        pick_up_notebook,
        give_notebook,
    ],
    history_len=8,
    main_camera=main_camera,
    camera_fov=90,
    servo_controler=servo_controler,
    debug_mode=True,
)

agent.task = "Approach blue notebook, grab it from the table and give it to human. Do not approach human until you grabbed a notebook."

agent.go()
```

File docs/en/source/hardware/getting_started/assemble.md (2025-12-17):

# ⚒️ Assembly



> Estimated Assembly time: From scratch: 2-4 hrs; with assembled SO100/SO101 arms: 1-2 hrs
> 
```{tip}
You can also buy [pre-assembled kits](https://github.com/TheRobotStudio/SO-ARM100#kits) for SO101 arms.

```

Official Assembly Videos from Wowrobo:
<iframe width="800" height="600" 
    src="https://www.youtube.com/embed/upB1CEFeOlk" 
    frameborder="0" 
    allowfullscreen>
</iframe>

Tips from Greg's Tech

<iframe width="800" height="600" 
    src="https://www.youtube.com/embed/Ezy3EepLSm4" 
    frameborder="0" 
    allowfullscreen>
</iframe>

## 🦾 SO101 Arms



> If you already have 2x SO101 arms assembled with motors configured, skip.
>

- Build 2x SO101 arms by following [SO101 Step-by-Step Assembly Instructions](https://huggingface.co/docs/lerobot/so101) to build 2 identical follower arms with 2 sets of motors (both previous indexed as 1-6) for 2 control boards.
- Then continue to [configure the motors](https://huggingface.co/docs/lerobot/so101#configure-the-motors) for the SO101 arms. 
- Follow this [installation guide](https://github.com/TheRobotStudio/SO-ARM100/tree/main/Optional/SO101_Wrist_Cam_Hex-Nut_Mount_32x32_UVC_Module) to add wrist cameras.
- If you have [3M gripper tape](https://www.amazon.com/gp/product/B0093CQPW8/ref=ppx_yo_dt_b_search_asin_title?ie=UTF8&psc=1), now it's time to wrap it on the fingers.

## 🤔 Configure Motors



> Since the official lerobot codebase currently doesn't support motor configuring besides the arm, we use [Bambot](https://bambot.org/) instead (works on Windows and Mac, Linux needs 'sudo chmod 666 /dev/ttyACM0' first).
>

- Connect the motor you want to configure (one-by-one) to a control board, and directly connect the board to your computer. 
- Navigate to [the motor configuration page of Bambot](https://bambot.org/feetech.js), establish the connection and scan for your servo motor.
  

- Rename the motor id following the instruction below.
  

- You need to configure two sets of motors for 2 motor control boards in addition to the SO101 arms:
    - one for **head** (motor ids: 7, 8)
    - and the other for **the wheel base** (motors ids: 7, 8, 9).
- Tips: write the numbers on motors with marker and distinguish motors for different boards (such as L1-L8 and R1-R9).

## 🛒 IKEA Cart

- Just in case you accidentally throw your manual away, [here it is](https://github.com/Vector-Wangel/XLeRobot/blob/main/others/Manuals_raskog_utility_cart.pdf).



## 🧑‍🦼‍➡ Wheel Base

> If you already have a Lekiwi base, detach the battery, servo mounts, etc. Base plate will only have 3 mounted motors with wheels (keep the wirings).
>



```{note}
Don't choose the wrong plate, each plate comes in a certain order.
```

- Mount the omni-wheels to the plate according to the figure above.
  - The specific motor id should be installed accordingly.
- Note that the connector of the omni-wheel needs 3x M4 screws.
- Wiring the motors regularly as the [tutorial](https://github.com/SIGRobotics-UIUC/LeKiwi/blob/main/Assembly.md#2-bottom-plate-assembly), after that instead of connecting the motor cable to the control board, use the extended wire/connector kit to extend the wire.



- Mount the top plate according to the figure above.
- Leave the motor cable hanging ,don't pull it out from the top plate just yet.



- Mount 3x connectors on the top plate according to the figure above.

```{tip}
Put the Lekiwi base with the connectors under the cart to see whether it can give enough pressure to the cart, with four wheels of the cart can still touch the ground. If not, try to modify the connectors' 3D model by slightly adjust the z-axis scale directly in the slicer software (keeping the xy-axis scale unchanged) and print them again.
```



```{tip}
Flip the cart over to do the assembly below.
```

- Now install the Lekiwi base with the connectors onto the bottom of the IKEA cart, with the thinner plate on the other side.
- Refer to the figure to find the desired assembly direction based on the motor index. 

```{note}
This new hardware version is compatible with the IKEA cart metal mesh, and all the 12 M3 screws should be able to fit in easily.
```



- Use needle-nose pliers to cut out the metal mesh at the corresponding holes in the top base, removing only the central "x" to maintain structural integrity. This creates openings for cable routing.
- Then, run the previously extended wire up through the cart from below.

## 🦾 Arm Base

### Top Base Assembly


- Easier assembly when the base is flipped over.

### Head Assembly



- It should be the same as the first two steps of [SO101 arm assembly](https://huggingface.co/docs/lerobot/so101#joint-1).

## 🧵 Wiring

```{important}
Complete all wiring and cable management for the top base and put the Raspberry Pi in its case before clamping the top base into the IKEA cart.
```



- Prepare the extended 5264 wire with the connector kit if you don't have one already.
- Use needle-nose pliers to cut out the metal mesh at for the upper two layers for cable routing, similar to the bottom layer previously. Choose the location as needed.
```{note}
When extending the 5264 wire yourself, be careful with the polarity—reversed connections will cause errors.
```
- Connect the extended 5264 **motor cable** from **the Lekiwi base** to **one of the SO101 arms** (this makes the base and the arm as Lekiwi).
- Connect the 2 **USB-C to USB-A** **data cables** from 2 **motor control board** to **Rasberry Pi** (2 USB-A slots left for the cameras).
- Connect all 3 **power cables**: 2 **USB-C to DC(12V)** from 2 **motor control board** and 1 **USB-C to USB-C** from **Rasberry Pi**, to the fast charging section of the power supply. Each slot provides up to 100W power when charging simultaneously, which is tested sufficient for 12V version operation.

### 🔋 Place the Battery 🛒

- Anywhere you like on the middle or lower level of the cart to maintain a low center of mass. The battery has an anti-slip bottom so it won't easily slide during normal operations.
- Maintain placed upright for safety.
- Just in case you also accidentally throw the battery manual away, [here it is](https://github.com/Vector-Wangel/XLeRobot/blob/main/others/Manual_Anker_SOLIX_C300_DC_Portable_Power_Station.pdf).

```{important}
In order to protect the motor control board, make sure to connect the power cables last. And always disconnect the power cables when plugging/unplugging other cables.
```
## 📸 Final Assembly

### Base into the Cart

```{important}
Complete all wiring and cable management for the top base and put the Raspberry Pi in its case before clamping the top base into the IKEA cart.
```



- Be careful not to break the case when you jam the IKEA cart edge into the case socket.
- For easier testing, the SO101 arms clamp directly onto the cart. Position the [arm bases](https://github.com/Vector-Wangel/XLeRobot/blob/main/3D_Models/3D_models_for_printing/XLeRobot_special/SO_5DOF_ARM100_Assemblybases.stl) at the two corners of the cart's top layer, then secure with clamps.
- Don't forget to put the bambulab filament cardboard spool inside to provide stable structural support if you have one.

After these steps, the XLeRobot should be physically well-built and ready to do some chores.





```{important}
Once XLeRobot is fully assembled, do not push it around like the IKEA cart, as this can damage the motor gears. Instead, lift the robot (~12kg) whenever you need to move it manually.
```
```{note}
Current form of the wheel connector is not strong, occasionally rescrewing the center screw may be needed.
```
### Optional Visual Upgrades

For better visual outlook, you can wear these parts to XLeRobot if you like. 



- **Shells** for the Control board and the first joint for better protection and visual.
  - You may need to take off the hand camera first before wearing the 2nd shell onto the arm.
- Sports sleeves to hide the cables and make XLeRobot more sleek.
  


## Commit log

2025-12-03 0.4.0 update
    [Gimbal_mesh_all_d435.stl, Gimbal_mesh_all_d455.stl]
2025-12-17 Fix YouTube link to use embed format
    Updated YouTube embed link format in the assembly guide.
2025-12-21 feat(ipol): add joint interpolator
2025-12-28 update pi05 doc
    [XLeRobot040_dualwheelbase.step]

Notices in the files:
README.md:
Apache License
